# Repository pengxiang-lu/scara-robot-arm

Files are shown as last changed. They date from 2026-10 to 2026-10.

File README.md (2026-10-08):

# 下棋机器人：三轴 SCARA 机械臂控制系统

本项目是下棋机器人，包含三轴 SCARA 机械臂的 STM32 下位机固件、Qt 串口上位机，以及机械结构模型和设计文档。系统支持笛卡尔坐标运动、PS2 手柄控制、末端气泵取放和语音播报。

## 项目效果图

以下为三维模型中的整机装配视图：

| 整机俯视效果 | 整机正视效果 |
| --- | --- |
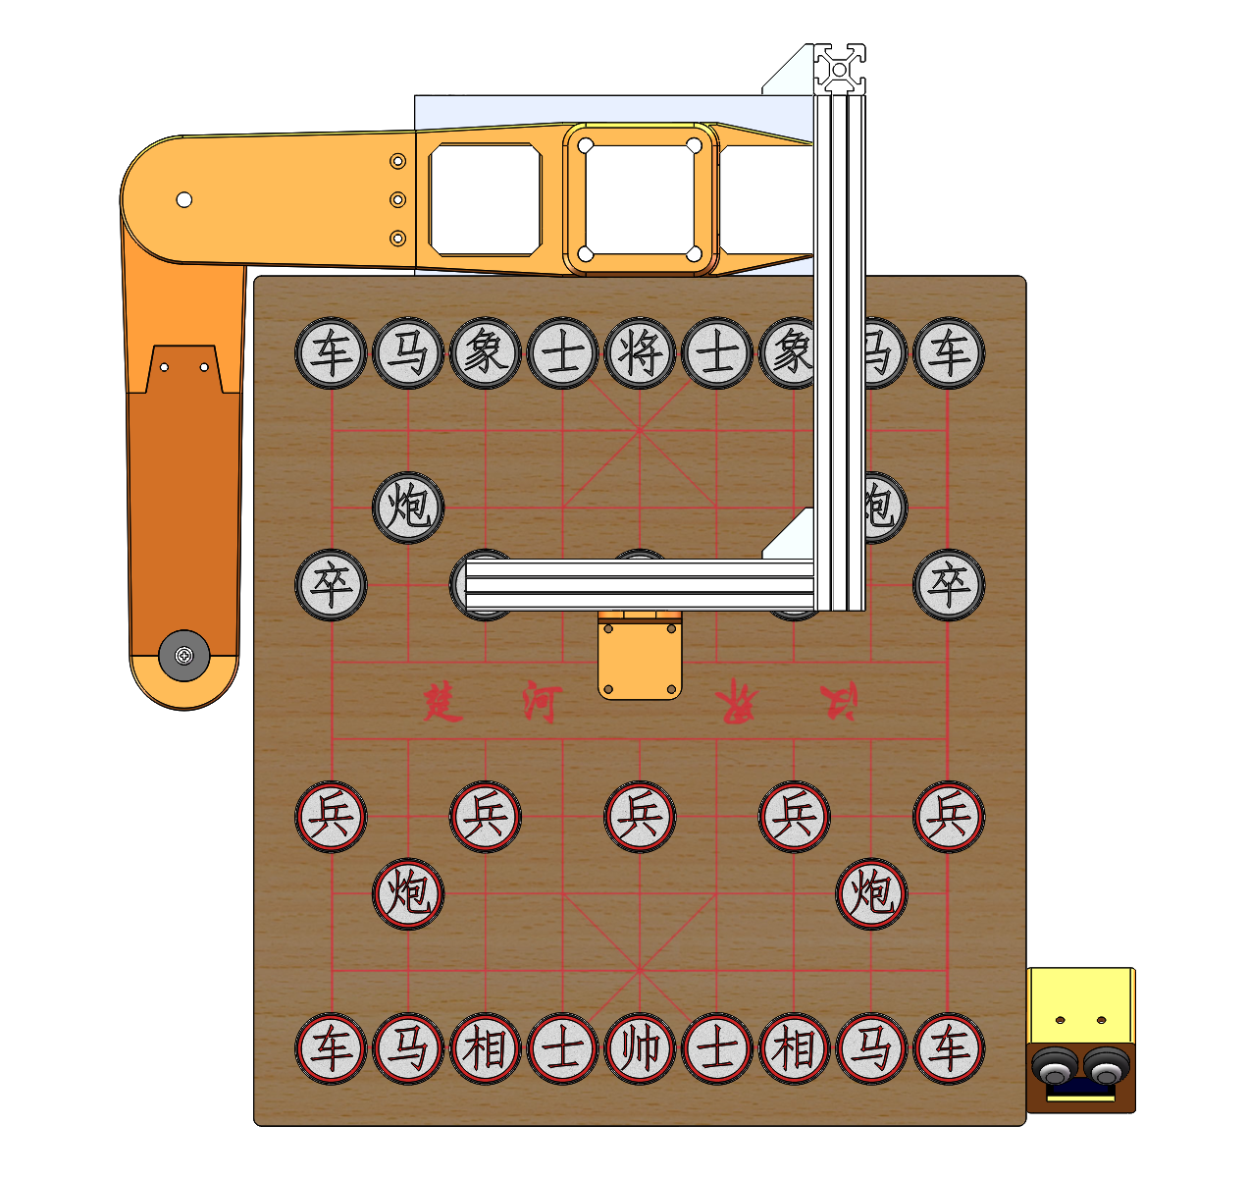
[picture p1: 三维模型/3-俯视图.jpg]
下棋机器人整机俯视三维效果图
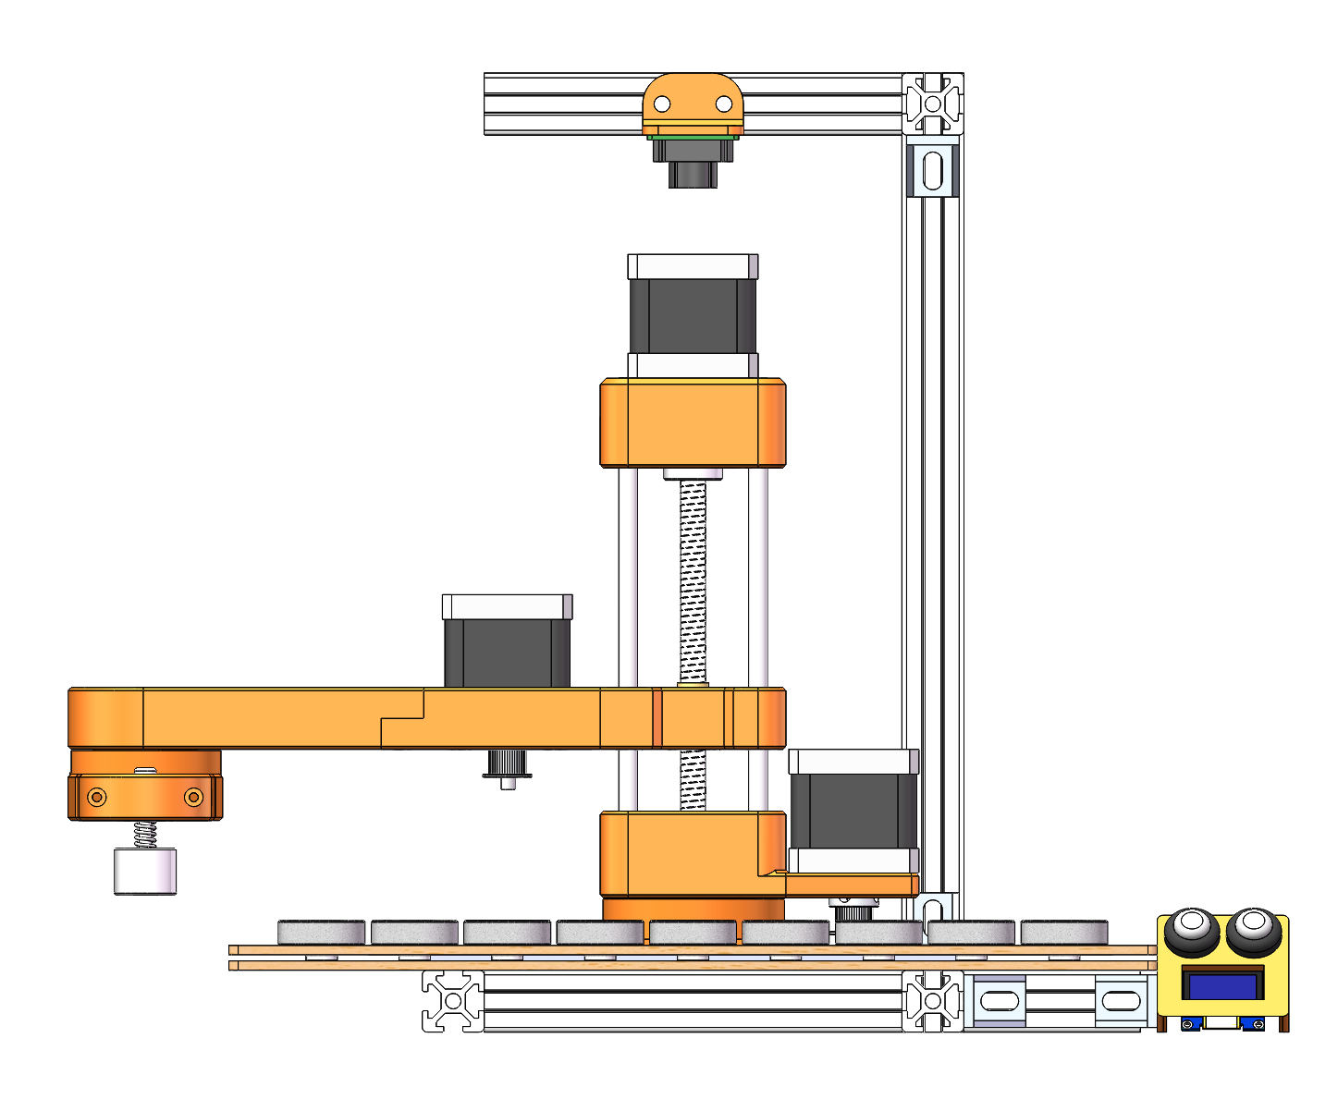
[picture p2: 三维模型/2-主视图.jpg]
下棋机器人整机正视三维效果图
|  |  |

真实照片：

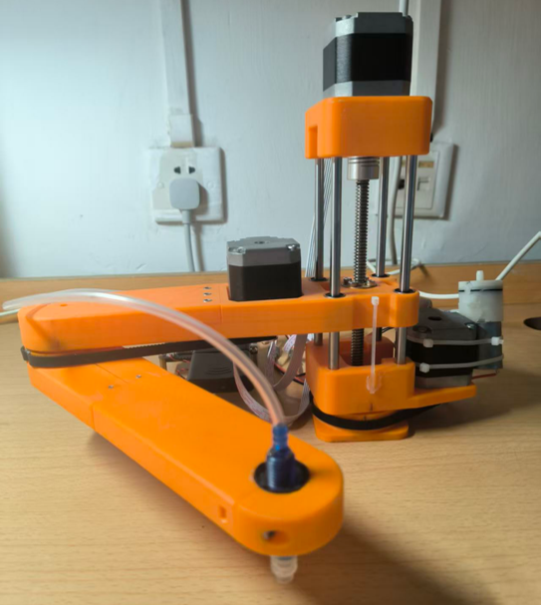
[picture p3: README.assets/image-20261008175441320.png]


驱动电路板：

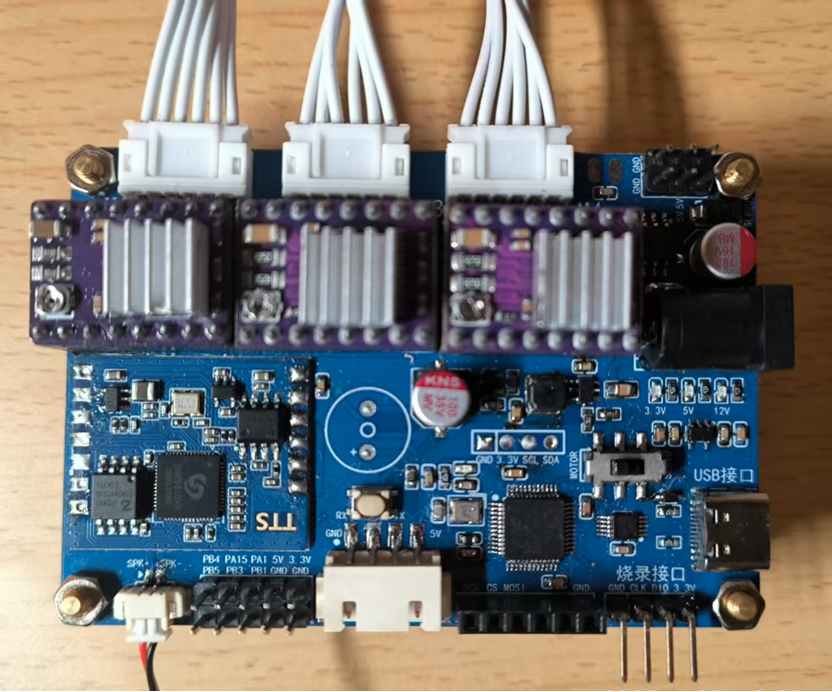
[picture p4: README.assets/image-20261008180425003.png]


上位机照片：

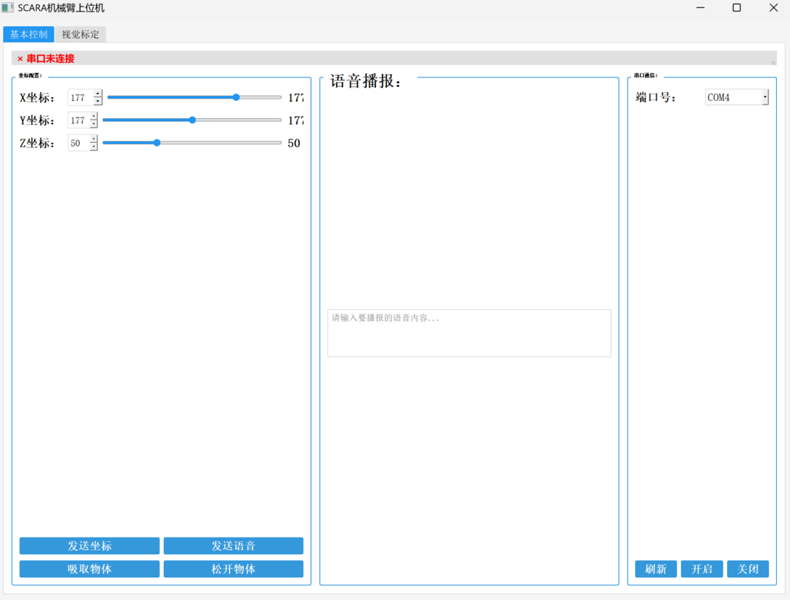
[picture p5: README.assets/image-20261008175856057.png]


	仿真照片：

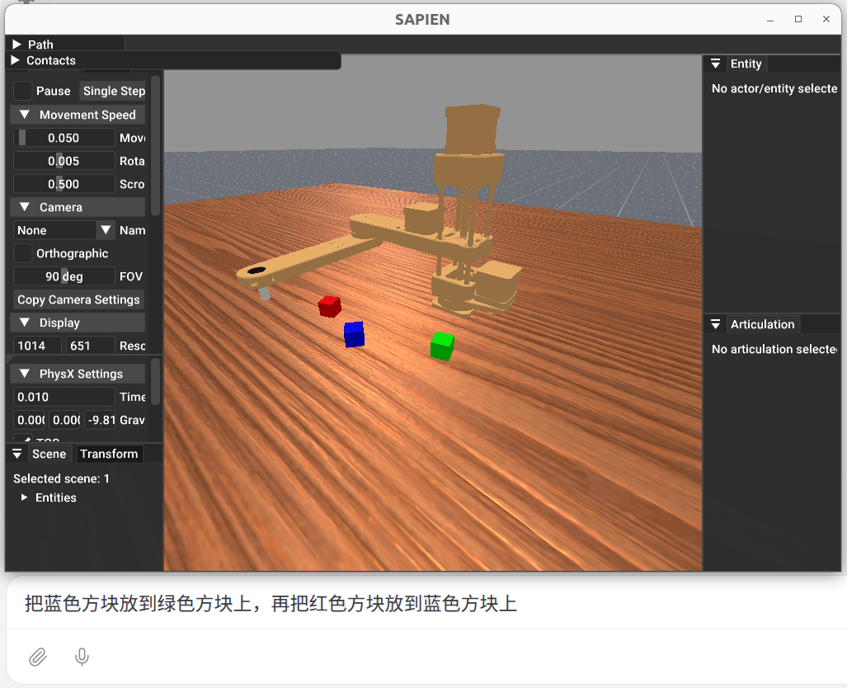
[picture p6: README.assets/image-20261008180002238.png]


## 功能概览

- **三轴 SCARA 运动控制**：下位机执行平面双连杆与 Z 轴运动学解算，将末端坐标转换为步进电机运动。
- **串口上位机控制**：通过 Qt 桌面程序选择串口、设置末端坐标、发送语音文本以及控制工具取放。
- **PS2 手柄遥控**：下位机读取手柄输入，支持直接控制机械臂末端及工具。
- **末端工具控制**：驱动气泵完成物块吸取和放下；固件配置中当前选择气泵方案。
- **语音播报**：通过串口向 SNR9816 模块发送文本。
- **机械结构与硬件资料**：提供机械臂、棋盘、PCB 等模型文件和设计笔记。

## 系统组成

| 部分 | 说明 |
| --- | --- |
| 下位机 | STM32F103C8，基于 STM32F10x 标准外设库；负责串口协议解析、运动学解算、三路步进电机、工具、PS2 和语音模块控制。 |
| 上位机 | Qt Widgets/C++ 桌面程序，使用 Qt SerialPort；提供串口连接、坐标控制、文本播报和工具控制。 |
| 机械结构 | 三轴 SCARA 机械臂，主、副臂长度参数各为 177 mm；步进电机经传动机构驱动。 |
| 驱动与供电 | 设计资料中包含 DRV8825 步进电机驱动、12 V 主电源及控制/语音模块供电方案；以实际装配和电路版本为准。 |

## 目录结构

```text
.
├── GUI/                         # Qt/C++ 上位机工程
│   ├── scara_HMI.pro             # qmake 工程文件
│   ├── mainwindow.*              # 界面与串口操作
│   └── roboticarm.*              # 上位机数据包封装
├── 下位机代码/                   # STM32 下位机工程
│   ├── Project.uvprojx            # Keil µVision 工程
│   ├── User/                      # main 与中断入口
│   ├── Hardware/                  # GPIO、串口、电机、语音等底层驱动
│   ├── Software/                  # SCARA 运动学、步进电机与协议逻辑
│   ├── Library/                   # STM32F10x 标准外设库
│   └── 通讯格式.txt               # 串口协议简表
├── URDF模型/                     # URDF 与网格模型
├── 三维模型/                     # 机械臂、棋盘及电路板等三维设计文件
└── 设计笔记/                     # 硬件与机械设计记录
```

## 构建与运行

### Qt 上位机

依赖：

- Qt 6（工程使用 C++17）
- Qt SerialPort 模块
- 与 Qt 套件匹配的 C++ 编译器（仓库现有构建目录对应 Qt 6.7.3 / MSVC 2019 64-bit Debug）

使用 Qt Creator 打开 [`GUI/scara_HMI.pro`](GUI/scara_HMI.pro)，选择已安装的桌面 Qt 套件，确认安装并启用 Qt SerialPort 后构建、运行。连接设备前，先通过界面刷新串口列表并选择端口。

上位机串口参数为 **115200 baud、8 数据位、无校验、1 停止位、无流控**。PC 与控制板之间需要使用匹配的 USB 转串口接口，并确保共地及电平兼容。

### STM32 下位机

使用 Keil MDK-ARM / µVision 打开 [`下位机代码/Project.uvprojx`](下位机代码/Project.uvprojx)。工程目标器件配置为 STM32F103C8，并依赖工程内的 STM32F10x 标准外设库。构建后按实际控制板的下载接口和时钟/引脚配置烧录固件。

上电后固件初始化电机、串口、语音模块和 PS2 手柄，并将末端坐标复位到 `X_INIT/Y_INIT/Z_INIT`。机械臂尺寸、减速比、Z 轴丝杆导程、运动范围等参数集中在 `下位机代码/Software/driver_config.h` 中；更改前请核对实际机构和驱动板配置。

> 首次联调请先断开或卸载末端工具，在安全范围内验证坐标和运动方向；坐标复位依赖当前固件设定，不等同于带限位开关的自动寻零。

## 串口协议

多字节坐标使用**大端序**传输，坐标在下位机侧按 `int16_t` 解释；校验和为指定字节求和后取低 8 位。坐标单位按固件中的机械尺寸参数以毫米配置。下列数据包均从上位机发往下位机。

| 包头 | 格式 | 校验/行为 |
| --- | --- | --- |
| `0x55` | `55 X高 X低 Y高 Y低 Z高 Z低 校验` | 校验为包头与 6 个坐标字节之和的低 8 位。下位机执行坐标移动；不可达时返回 `Target position unreachable\r\n`。 |
| `0x66` | `66 文本字节... 00` | 文本以 NUL 结尾，不带校验和。设计协议为 GBK 编码；发送端需与语音模块的字符编码保持一致。完成后返回 `Voice executed successfully\r\n`。 |
| `0x77` | `77 工具状态 校验` | `01` 吸取、`00` 放下；校验为包头与状态字节之和的低 8 位。 |
| `0x88` | `88 X高 X低 Y高 Y低 Z高 Z低 工具状态 校验` | 校验为包头及全部 7 个数据字节之和的低 8 位。依次执行工具状态变化和坐标移动；完成时返回 `Action executed successfully\r\n`，不可达时返回 `Target position unreachable\r\n`。 |

`0x55`、`0x77` 和 `0x88` 均由下位机校验后处理。上位机当前界面直接发送 `0x55`、`0x66` 和 `0x77`；`0x88` 可供兼容协议的客户端使用。

## 注意事项

- 运动范围和坐标系由固件配置及机械装配决定。更换连杆、传动比、丝杆或工具后，应重新校准参数并验证可达范围。
- 语音文本编码需与语音模块一致；Windows 上位机使用本地编码转换，跨系统运行时请特别检查字符编码。

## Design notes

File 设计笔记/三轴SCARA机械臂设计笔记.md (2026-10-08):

# 三轴SCARA机械臂设计笔记

## 一、机械

### 1. 机械臂

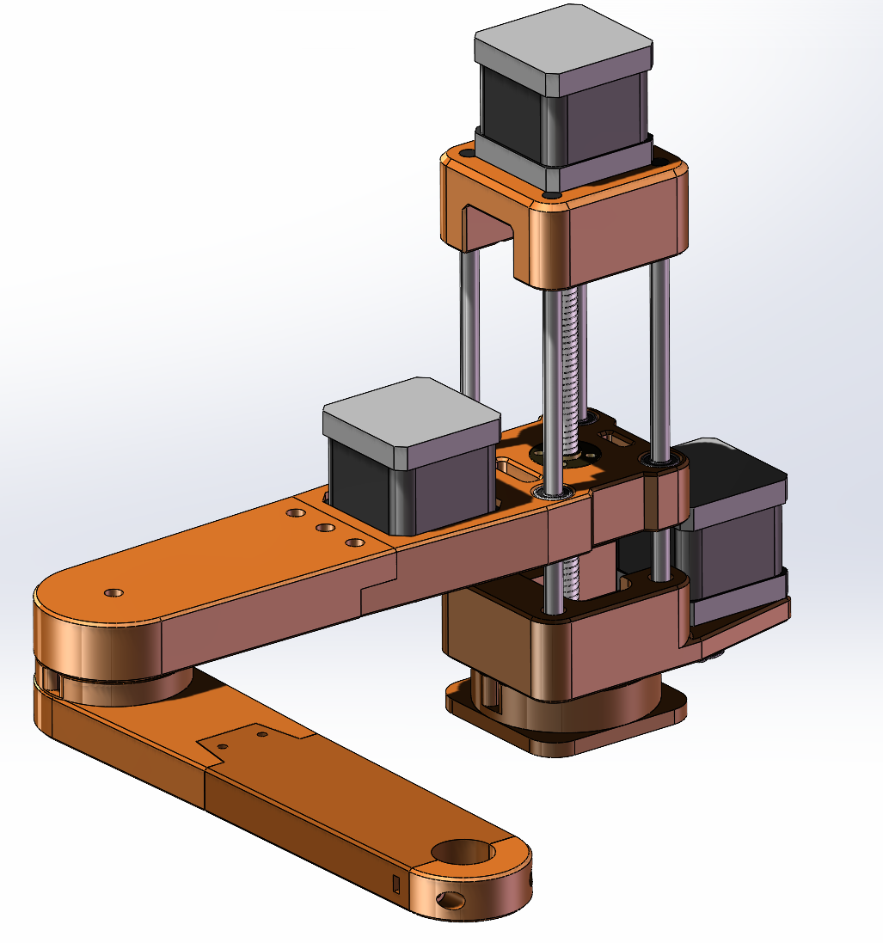
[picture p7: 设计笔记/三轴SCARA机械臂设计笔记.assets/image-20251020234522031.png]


使用的机械臂是复刻了网络上开源的一个三轴SCARA机械臂（https://community.aijishu.com/a/1060000000361674），使用三个步进电机加上皮带传动驱动机械臂的运动，机械臂3D模型如上图所示。

### 2. 步进电机

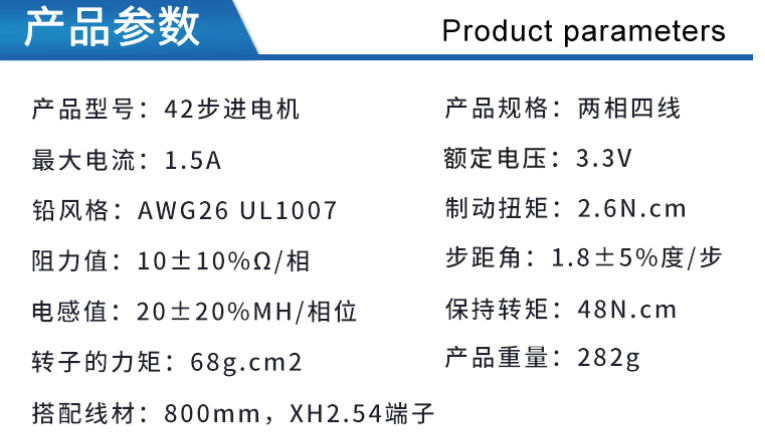
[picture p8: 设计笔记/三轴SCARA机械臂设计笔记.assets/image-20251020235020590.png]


这是使用的步进电机的参数，产品介绍上面写的是3.3V额定电压，然后问了厂家实际上9~36V的电机供电电压都可以。所以设计上采用常用的12V供电。

### 3. 电磁铁

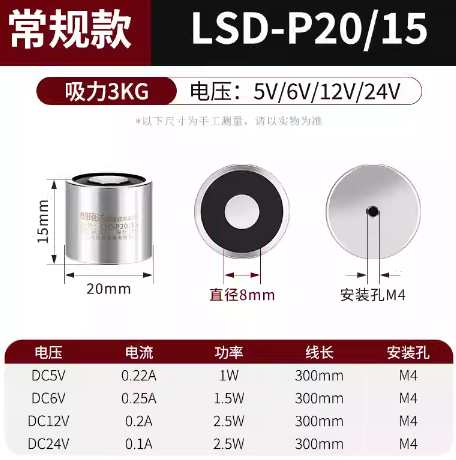
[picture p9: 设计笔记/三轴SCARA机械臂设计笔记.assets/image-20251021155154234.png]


使用了12V的电磁铁来吸取棋子。

但是后面发现对棋子的吸力不够而且只能吸附磁性物体。

所以后面更改了方案，使用气泵和磁通阀来实现物体的拾取。

### 4. 气泵

电磁铁只能吸取磁性物体，而且对棋子的吸力不足，因此改用气泵配合气路末端吸盘完成取放。气泵由下位机控制，取物和放物分别执行不同的输出时序。

当前固件在 `driver_config.h` 中将 `TOOL` 配置为 `AIRPUMP`。`tool.c` 使用 TIM1 的两个 PWM 通道控制气泵相关输出，PWM 频率为 50 Hz；取物和放物时切换通道的比较值，并各延时约 800 ms。气泵及阀的具体型号、气路连接方式和 PWM 比较值与实际执行器的对应关系，应以实物接线和调试结果为准。

## 二、硬件

使用语音播报，三路步进电机驱动，一路有刷电机驱动，还要有远程控制的下位机电路，所以下面考虑如何设计这个电路。

### 1. 语音模块

理论上可以使用直接像DY-SV17F这样的USB提前下载要播报语音的模块，但是打算使用SNR9816TTS模块来实现语音播报。

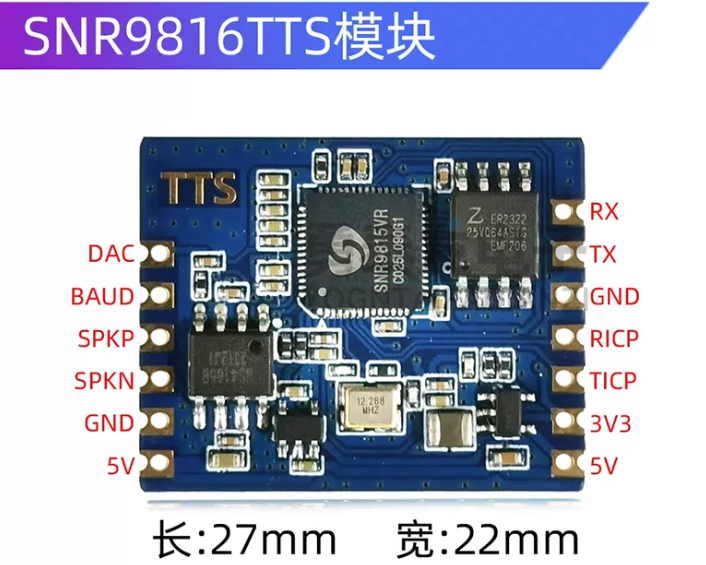
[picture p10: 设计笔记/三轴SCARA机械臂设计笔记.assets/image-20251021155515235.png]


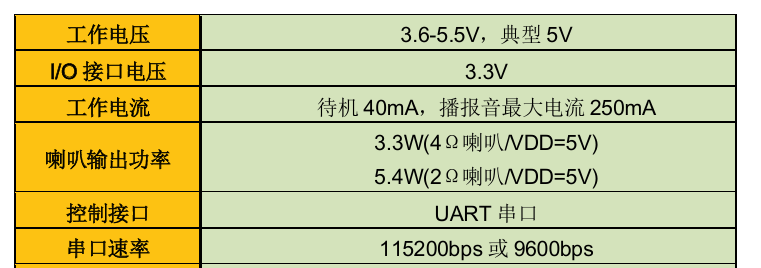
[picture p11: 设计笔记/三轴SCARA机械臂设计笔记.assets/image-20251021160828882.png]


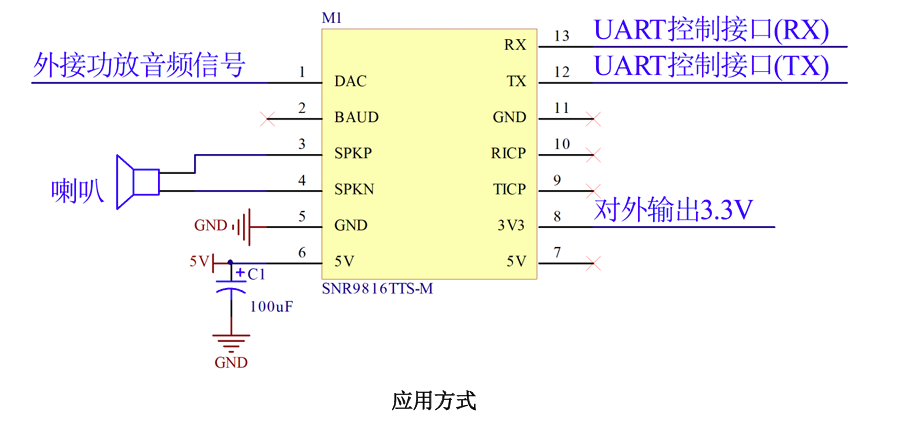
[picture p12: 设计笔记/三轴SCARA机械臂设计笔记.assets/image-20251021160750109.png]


### 2. 步进电机驱动模块

由于电机参数上面写的是最高电流1.5A，所以采用DRV8825绰绰有余，而且比传统的A4988步进电机驱动的要好用很多。

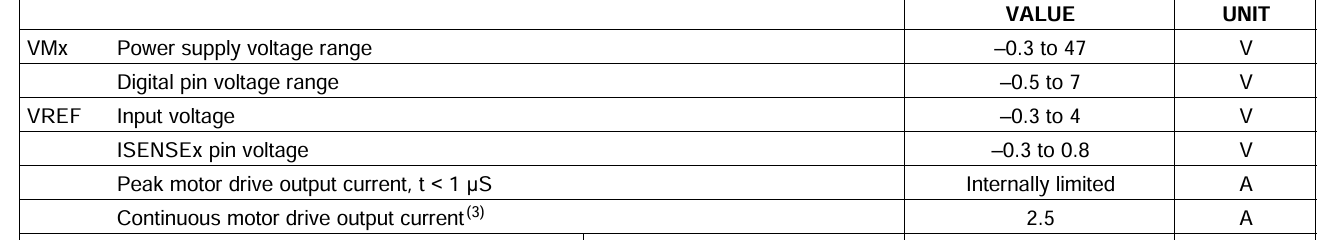
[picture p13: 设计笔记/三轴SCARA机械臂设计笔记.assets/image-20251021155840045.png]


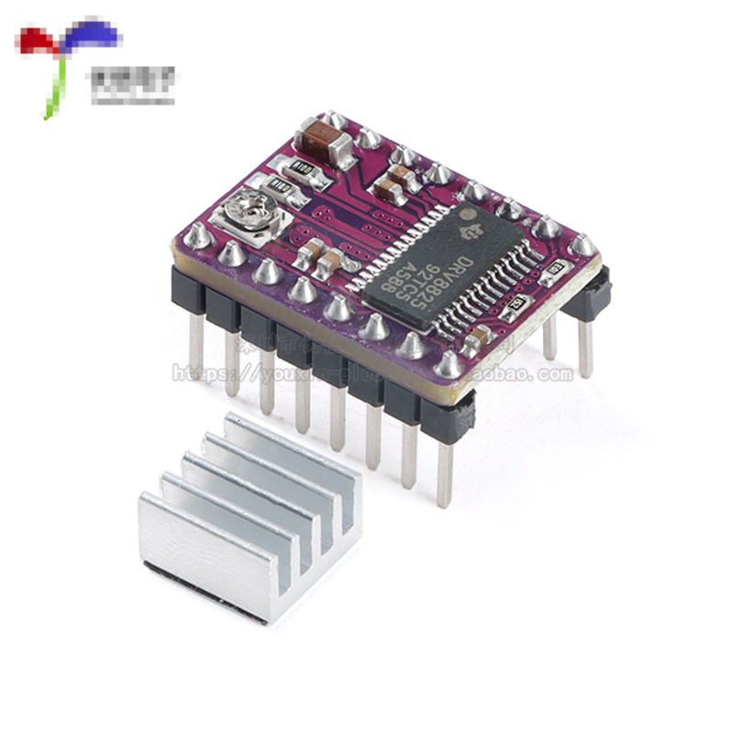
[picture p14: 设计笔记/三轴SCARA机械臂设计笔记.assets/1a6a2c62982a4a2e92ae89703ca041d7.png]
1a6a2c62982a4a2e92ae89703ca041d7


### 3. 有刷电机驱动模块

由于只需要一路有刷电机驱动，而且电流要求较小，所以电机采用L9110S电机驱动，工作电压2.5V~12V，最大持续电流1.2A，最大电流2A满足电流需求。这是手册里给的参考电路：

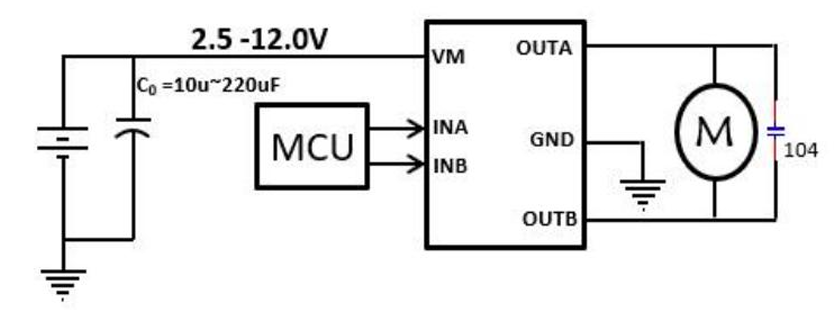
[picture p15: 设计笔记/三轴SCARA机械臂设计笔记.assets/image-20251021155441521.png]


### 4. 电源树

由于使用的是12V主电源供电和3.3V控制电路供电，而且语音播报模块要5V供电，所以要分别将12V降压到5V和3.3V，所以可以使用如下方案：

首先使用TPS563201这款DCDC电源芯片将电压降到5V，再通过LDO将5V电压降压到3.3V。原理图如下：

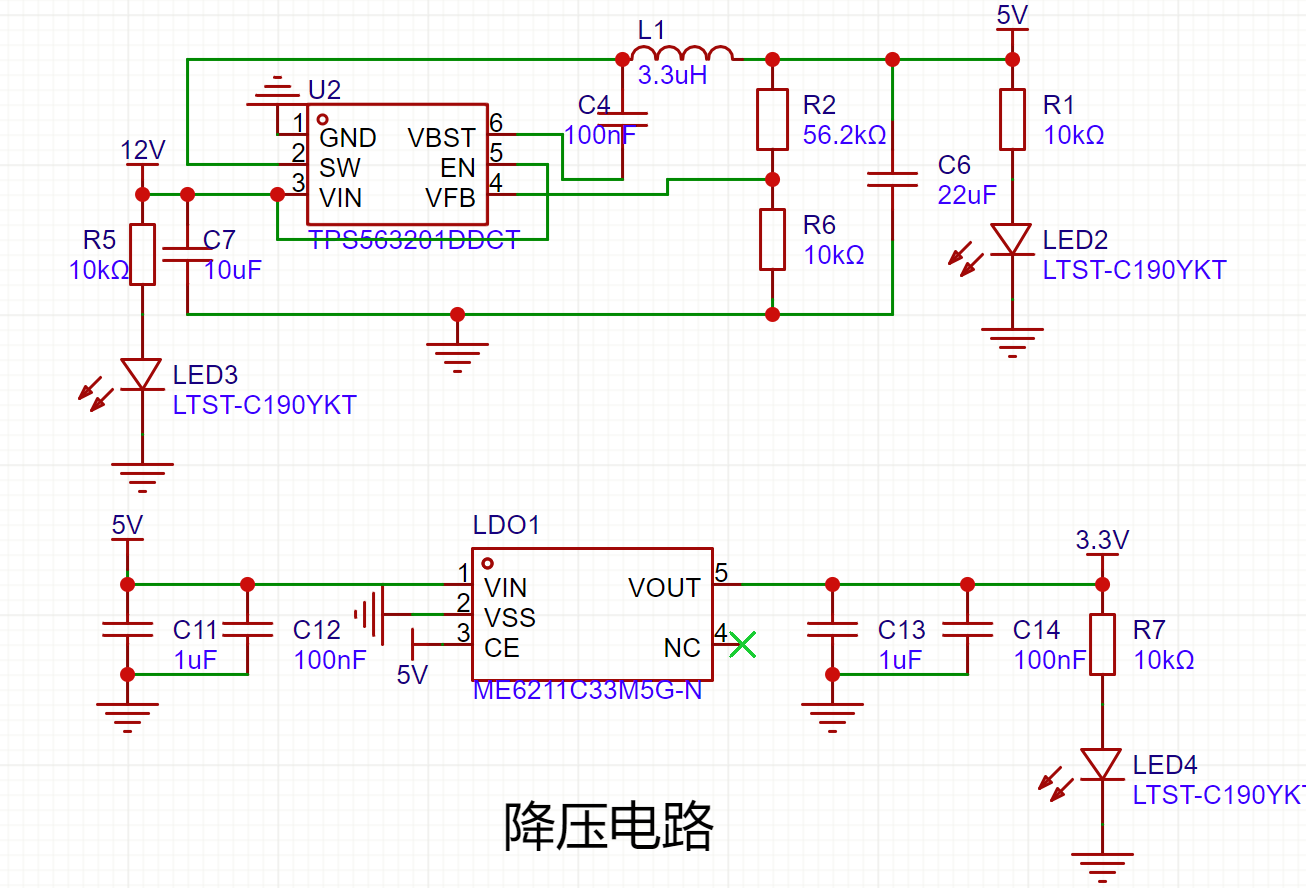
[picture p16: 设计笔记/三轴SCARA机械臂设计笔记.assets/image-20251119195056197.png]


## 三、下位机控制算法

### 1. 步进电机驱动

机械臂的 FA（主臂）、SA（副臂）和 Z（垂直丝杆）轴均使用步进电机。固件将电机步距角配置为 1.8°，细分数配置为 32；驱动器接收方向信号和脉冲信号，下位机分别使用 TIM2、TIM3、TIM4 产生三轴脉冲。PWM 占空比约为 50%，通过改变定时器自动重装载值调整脉冲频率，脉冲数决定电机的目标步数。

电机初始化时将角度和速度参数换算为细分脉冲参数。每个关节的脉冲数与角度关系为：

```text
每度脉冲数 = 细分数 / 步距角
目标脉冲数 = 目标角度变化 × 每度脉冲数 × 传动比
```

FA、SA 轴分别使用 5.1 和 3.9 的传动比；Z 轴根据 2 mm 导程换算，即每转对应 2 mm 的直线位移。运动过程中，固件按目标脉冲数和设定速度规划加速、匀速及减速区间：加速与减速过程依据匀加速关系计算脉冲速度，再换算成定时器周期；短距离运动无法达到最高速度时，则缩短加减速区间。定时器更新中断负责累计已输出的脉冲，达到目标脉冲数后停止对应定时器。三轴运动分别运行，主循环等待各轴完成后结束本次坐标移动。

当前固件中 FA、SA 初始化参数为加速度 50°/s²、最高速度 30°/s、最低速度 10°/s；Z 轴电机初始化参数为加速度 80°/s²、最高速度 80°/s、最低速度 15°/s（按电机转角速度配置，再通过丝杆导程换算为直线运动）。修改这些参数前，应结合电机、驱动器电流、负载和机械传动进行实际测试。

### 2. 机械臂解算

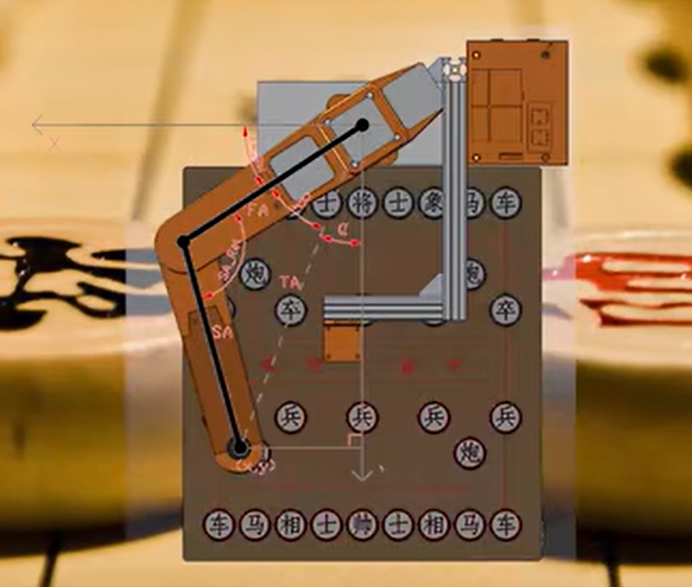
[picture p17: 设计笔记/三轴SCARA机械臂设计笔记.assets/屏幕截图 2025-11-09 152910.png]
屏幕截图 2025-11-09 152910


	这是机械臂的三个轴的定义：FA（主臂），SA（副臂），Z（垂直丝杆）

机械臂在 XY 平面内由两段连杆构成，FA 为主臂关节，SA 为副臂关节；Z 轴通过丝杆带动末端上下移动。固件参数中两段连杆长度均为 177 mm，末端坐标使用毫米表示。

上位机发送末端坐标 `(x, y, z)` 后，下位机先进行逆运动学求解。令 `L1`、`L2` 分别为两段连杆长度，`r² = x² + y²`，按当前固件采用的坐标轴和关节角定义计算：

```text
r² = x² + y²
SA = acos((L1² + L2² - r²) / (2 × L1 × L2)) × 180° / π
alpha = atan2(-y, x) × 180° / π
beta = acos((L1² + r² - L2²) / (2 × L1 × sqrt(r²))) × 180° / π
FA = 90° - alpha - beta
```

三角函数求解得到的角度换算为度数后，再与关节限位比较。当前固件配置的 FA 范围为 -90° 至 90°，SA 范围为 15° 至 180°，Z 高度范围为 2 mm 至 83 mm；超出连杆可达区域或关节限位时拒绝运动。通过检查后，下位机根据目标角度差、传动比、细分数以及 Z 轴导程计算各电机的目标脉冲数，并驱动三轴运动。

坐标初始化目前使用固件中设定的 `(177, -177, 25)`，这是程序写入的初始坐标，并非限位开关或编码器反馈得到的真实机械原点。搬运机构或机械臂时应重新确认初始姿态和坐标对应关系。

**实现注意：**逆运动学得到的关节角以度为单位；检查或使用正运动学实现时，应确认传入 `sin`/`cos` 的角度已转换为弧度，并验证关节角定义与图中的坐标轴方向一致。

## 四、物料清单

暂定

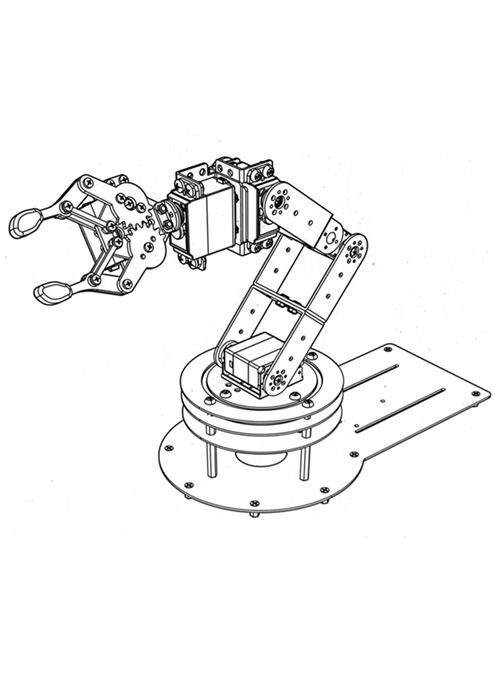
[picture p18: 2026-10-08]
GUI/image/robotic_arm_image.png

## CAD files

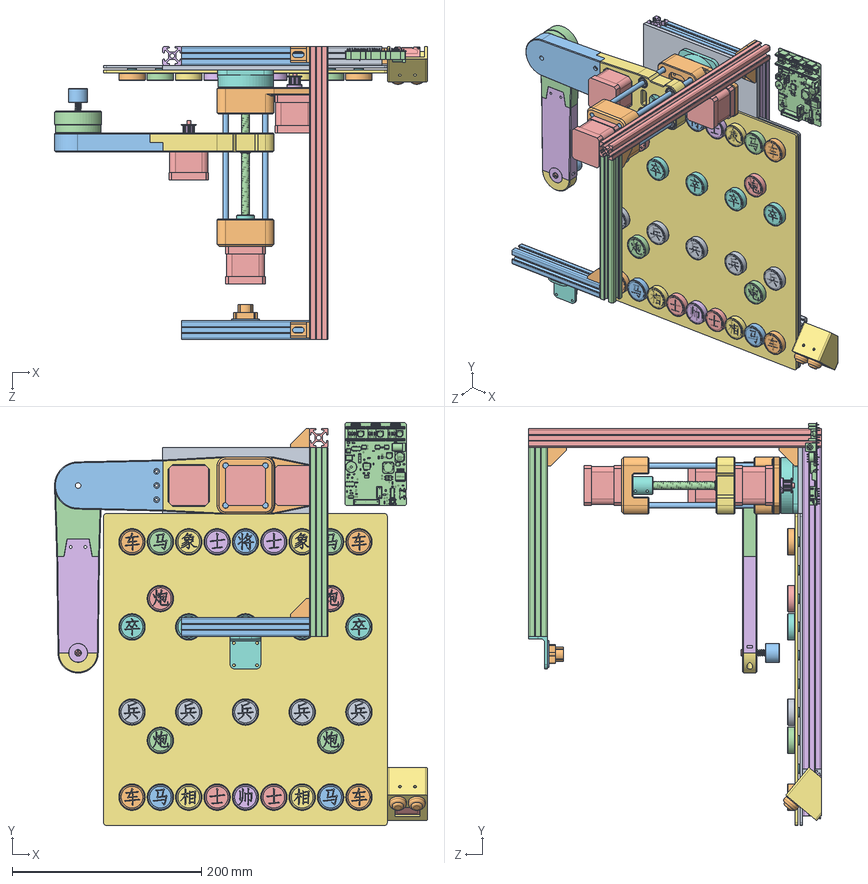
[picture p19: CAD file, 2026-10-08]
三维模型/总装配体/象棋机器人装配体.SLDASM
394.5 x 426.2 x 310.0 mm
亚克力底座
2020角件 x 12
2020型材135mm x 4
2020型材200mm
2020型材310mm
2020型材390mm x 2
棋盘正面
磁铁 x 122
棋盘底面
棋子-黑車 x 2
棋子-黑将
棋子-黑马 x 2
棋子-黑炮 x 2
棋子-黑士 x 2
棋子-黑象 x 2
棋子-黑卒 x 5
棋子-红兵 x 5
棋子-红車 x 2
棋子-红马 x 2
棋子-红炮 x 2
棋子-红士 x 2
棋子-红帅
棋子-红相 x 2
x轴底座
6806轴承 x 2
x轴转台
光轴 x 4
丝杆
42步进 x 3
GT2同步轮内孔5 x 2
x轴主臂1
联轴器
直线轴承 x 4
顶(丝杆z)
x轴主臂2加长3
y轴对称
686zz x 4
y轴副臂2加长3
末端固定
T8螺母
按钮螺母-新款 x 2
按钮-新款 x 2
电磁铁
电磁铁弹簧
电磁铁固定螺栓
电磁铁套筒
屏幕外壳3
摄像头支架
屏幕连接型材
mount lens
PCB
OLED模块

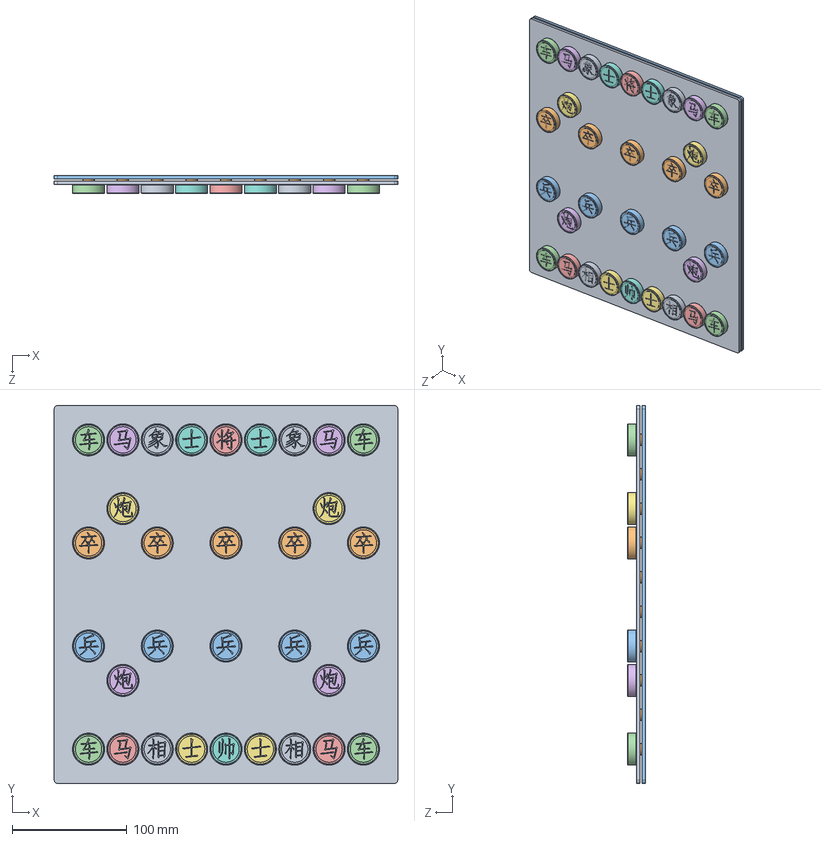
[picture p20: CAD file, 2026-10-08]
三维模型/棋盘装配体/棋盘装配体.SLDASM
300.0 x 330.0 x 16.0 mm
棋盘正面
磁铁 x 122
棋盘底面
棋子-黑車 x 2
棋子-黑将
棋子-黑马 x 2
棋子-黑炮 x 2
棋子-黑士 x 2
棋子-黑象 x 2
棋子-黑卒 x 5
棋子-红兵 x 5
棋子-红車 x 2
棋子-红马 x 2
棋子-红炮 x 2
棋子-红士 x 2
棋子-红帅
棋子-红相 x 2

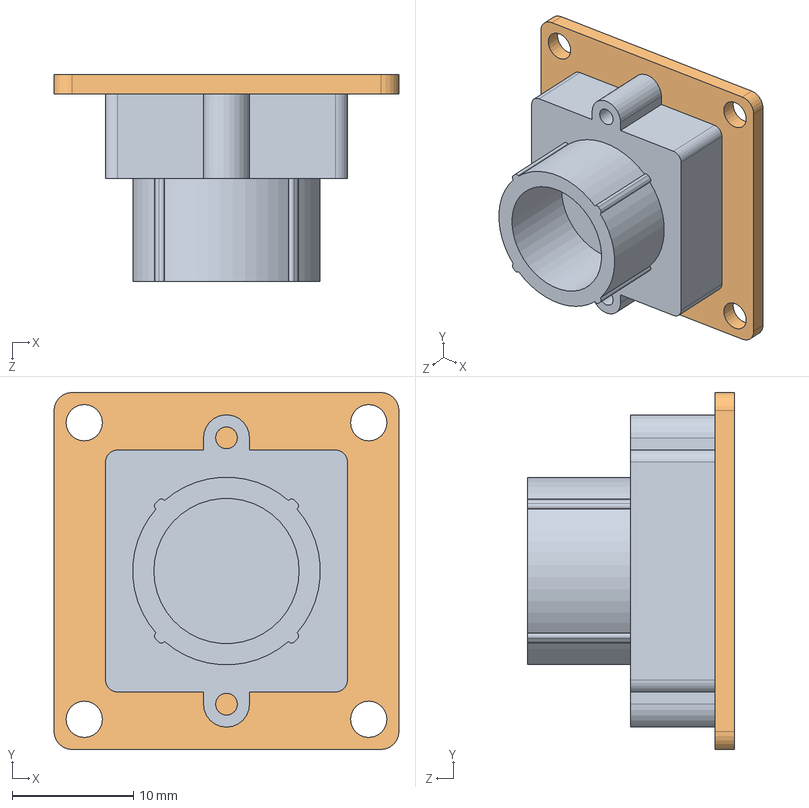
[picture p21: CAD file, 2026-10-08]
三维模型/摄像头装配体/摄像头.SLDASM
28.5 x 29.5 x 17.1 mm
mount lens
PCB

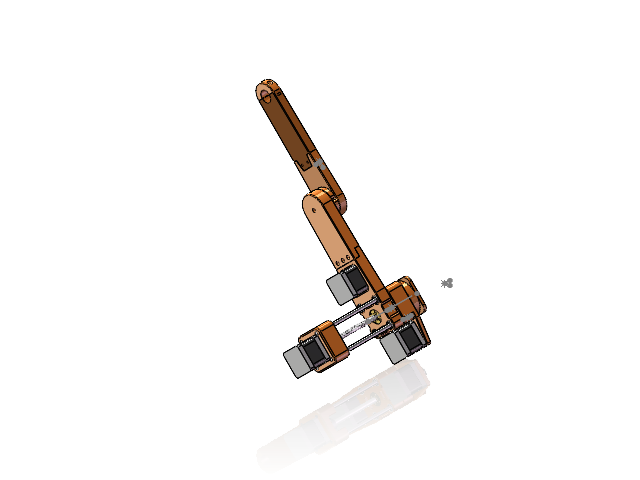
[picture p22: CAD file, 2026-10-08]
三维模型/机械臂装配体/机械臂装配体.SLDASM
x轴底座
6806轴承 x 2
x轴转台
光轴 x 4
丝杆
42步进 x 3
GT2同步轮内孔5 x 2
x轴主臂1
联轴器
直线轴承 x 4
顶(丝杆z)
x轴主臂2加长3
y轴对称
686zz x 4
y轴副臂2加长3
末端固定
T8螺母

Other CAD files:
三维模型/PCBv3.2装配体/C14.sldasm
三维模型/PCBv3.2装配体/J1.sldasm
三维模型/PCBv3.2装配体/R1.sldasm
三维模型/PCBv3.2装配体/U7.sldasm
三维模型/PCBv3.2装配体/C16.sldasm
三维模型/PCBv3.2装配体/D3.sldasm
三维模型/PCBv3.2装配体/D4.sldasm
三维模型/PCBv3.2装配体/C33.sldasm
三维模型/PCBv3.2装配体/R5.sldasm
三维模型/PCBv3.2装配体/U10.sldasm
三维模型/PCBv3.2装配体/U8.sldasm
三维模型/PCBv3.2装配体/U6.sldasm
三维模型/PCBv3.2装配体/C20.sldasm
三维模型/PCBv3.2装配体/R32.sldasm
URDF模型/scara_urdf/meshes/Link1.STL
URDF模型/scara_urdf/meshes/Link2.STL
URDF模型/scara_urdf/meshes/Link3.STL
URDF模型/scara_urdf/meshes/base_link.STL
URDF模型/scara_urdf_gripper/meshes/Link1.STL
URDF模型/scara_urdf_gripper/meshes/Link2.STL
URDF模型/scara_urdf_gripper/meshes/Link3.STL
URDF模型/scara_urdf_gripper/meshes/base_link.STL
URDF模型/scara_urdf_gripper/meshes/finger.stl
URDF模型/scara_urdf_gripper/meshes/hand.stl
URDF模型/scara_urdf_suction/meshes/Link1.STL
URDF模型/scara_urdf_suction/meshes/Link2.STL
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

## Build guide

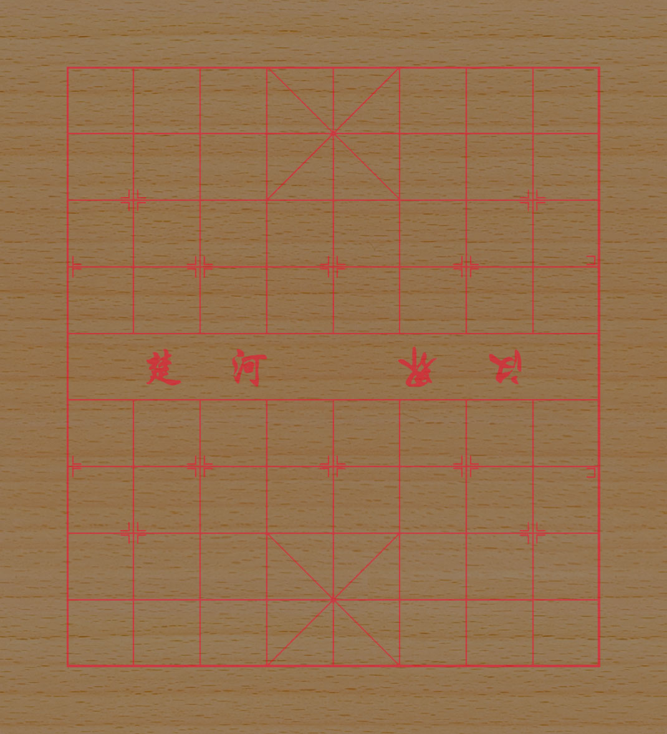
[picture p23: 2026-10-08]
三维模型/棋盘装配体/桉木棋盘.jpg

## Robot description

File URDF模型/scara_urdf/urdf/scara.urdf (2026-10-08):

<?xml version="1.0" encoding="utf-8"?>
<!-- This URDF was automatically created by SolidWorks to URDF Exporter! Originally created by Stephen Brawner (brawner@gmail.com) 
     Commit Version: 1.6.0-4-g7f85cfe  Build Version: 1.6.7995.38578
     For more information, please see http://wiki.ros.org/sw_urdf_exporter -->
<robot name="scara">
  <link name="base_link">
    <inertial>
      <origin xyz="-2.33602825269394E-08 0.000325855492130904 0.00700152226621419" rpy="0 0 0" />
      <mass value="0.0402568517427835" />
      <inertia ixx="1.16860689250314E-05" ixy="-1.8570220883558E-11" ixz="5.64103689843095E-12" iyy="1.1993754297666E-05" iyz="-7.8687526683924E-08" izz="2.18256266420959E-05" />
    </inertial>
    <visual>
      <origin xyz="0 0 0" rpy="0 0 0" />
      <geometry>
        <mesh filename="package://scara/meshes/base_link.STL" />
      </geometry>
      <material name="">
        <color rgba="1 0.533333333333333 0.176470588235294 1" />
      </material>
    </visual>
    <collision>
      <origin xyz="0 0 0" rpy="0 0 0" />
      <geometry>
        <mesh filename="package://scara/meshes/base_link.STL" />
      </geometry>
    </collision>
  </link>
  <link name="Link1">
    <inertial>
      <origin xyz="-5.82317828406263E-05 0.0125670372099185 0.106258424386727" rpy="0 0 0" />
      <mass value="0.326072004656768" />
      <inertia ixx="0.000175710230688168" ixy="1.48740556515632E-09" ixz="-1.85135692980239E-07" iyy="0.000155118181724295" iyz="5.77187163494193E-06" izz="0.000168999196132045" />
    </inertial>
    <visual>
      <origin xyz="0 0 0" rpy="0 0 0" />
      <geometry>
        <mesh filename="package://scara/meshes/Link1.STL" />
      </geometry>
      <material name="">
        <color rgba="1 0.533333333333333 0.176470588235294 1" />
      </material>
    </visual>
    <collision>
      <origin xyz="0 0 0" rpy="0 0 0" />
      <geometry>
        <mesh filename="package://scara/meshes/Link1.STL" />
      </geometry>
    </collision>
  </link>
  <joint name="joint1" type="revolute">
    <origin xyz="0 0 0" rpy="0 0 0" />
    <parent link="base_link" />
    <child link="Link1" />
    <axis xyz="0 0 1" />
    <limit lower="-1.57" upper="1.57" effort="0" velocity="0" />
  </joint>
  <link name="Link2">
    <inertial>
      <origin xyz="0.0757980106992246 -2.08571677094531E-06 -0.0051586157715495" rpy="0 0 0" />
      <mass value="0.269351505596376" />
      <inertia ixx="7.65002539967446E-05" ixy="-2.60368605877457E-09" ixz="3.17859629830699E-06" iyy="0.000236767952686508" iyz="2.56350182000798E-09" izz="0.000281158978903039" />
    </inertial>
    <visual>
      <origin xyz="0 0 0" rpy="0 0 0" />
      <geometry>
        <mesh filename="package://scara/meshes/Link2.STL" />
      </geometry>
      <material name="">
        <color rgba="1 0.533333333333333 0.176470588235294 1" />
      </material>
    </visual>
    <collision>
      <origin xyz="0 0 0" rpy="0 0 0" />
      <geometry>
        <mesh filename="package://scara/meshes/Link2.STL" />
      </geometry>
    </collision>
  </link>
  <joint name="joint2" type="prismatic">
    <origin xyz="0 0 0.0664" rpy="0 0 -1.5708" />
    <parent link="Link1" />
    <child link="Link2" />
    <axis xyz="0 0 1" />
    <limit lower="0" upper="0.091" effort="50" velocity="1" />
  </joint>
  <link name="Link3">
    <inertial>
      <origin xyz="0.0714052178204697 0.000746521706669515 -0.0279252348818434" rpy="0 0 0" />
      <mass value="0.155288189008471" />
      <inertia ixx="3.10970726600027E-05" ixy="-7.56646280633992E-07" ixz="5.77430535141398E-06" iyy="0.000121028450793099" iyz="-2.31665870998517E-09" izz="0.00014171550680783" />
    </inertial>
    <visual>
      <origin xyz="0 0 0" rpy="0 0 0" />
      <geometry>
        <mesh filename="package://scara/meshes/Link3.STL" />
      </geometry>
      <material name="">
        <color rgba="1 0.533333333333333 0.176470588235294 1" />
      </material>
    </visual>
    <collision>
      <origin xyz="0 0 0" rpy="0 0 0" />
      <geometry>
        <mesh filename="package://scara/meshes/Link3.STL" />
      </geometry>
    </collision>
  </link>
  <joint name="joint3" type="revolute">
    <origin xyz="0.177 0 -0.0061" rpy="0 0 0" />
    <parent link="Link2" />
    <child link="Link3" />
    <axis xyz="0 0 -1" />
    <limit lower="-2.8" upper="0" effort="0" velocity="0" />
  </joint>
</robot>

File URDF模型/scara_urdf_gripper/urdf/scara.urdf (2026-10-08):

<?xml version="1.0" encoding="utf-8"?>
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
<robot name="scara_with_gripper">

  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
  <link name="base_link">
    <inertial>
      <origin xyz="-2.33602825269394E-08 0.000325855492130904 0.00700152226621419" rpy="0 0 0" />
      <mass value="0.0402568517427835" />
      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
    </inertial>
    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
  </link>

  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
  <link name="Link1">
    <inertial>
      <origin xyz="-5.82317828406263E-05 0.0125670372099185 0.106258424386727" rpy="0 0 0" />
      <mass value="0.326072004656768" />
      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
    </inertial>
    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
  </link>

  <joint name="joint1" type="revolute">
    <origin xyz="0 0 0" rpy="0 0 0" />
    <parent link="base_link" />
    <child link="Link1" />
    <axis xyz="0 0 1" />
    <limit lower="-1.57" upper="1.57" effort="0" velocity="0" />
  </joint>

  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
  <link name="Link2">
    <inertial>
      <origin xyz="0.0757980106992246 -2.08571677094531E-06 -0.0051586157715495" rpy="0 0 0" />
      <mass value="0.269351505596376" />
      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
    </inertial>
    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
  </link>

  <joint name="joint2" type="prismatic">
    <origin xyz="0 0 0.0864" rpy="0 0 -1.5708" />
    <parent link="Link1" />
    <child link="Link2" />
    <axis xyz="0 0 1" />
    <limit lower="0.00" upper="0.071" effort="50" velocity="1" />
  </joint>

  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
  <link name="Link3">
    <inertial>
      <origin xyz="0.0714052178204697 0.000746521706669515 -0.0279252348818434" rpy="0 0 0" />
      <mass value="0.155288189008471" />
      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
    </inertial>
    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
  </link>

  <joint name="joint3" type="revolute">
    <origin xyz="0.177 0 -0.0061" rpy="0 0 0" />
    <parent link="Link2" />
    <child link="Link3" />
    <axis xyz="0 0 -1" />
    <limit lower="-2.8" upper="0" effort="0" velocity="0" />
  </joint>

  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
  <joint name="scara_to_gripper_joint" type="revolute">
    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
    <origin rpy="3.14 0 0" xyz="0.177 0 -0.03"/>
    <parent link="Link3"/>
    <child link="panda_hand"/>
    <axis xyz="0 0 -1" />
    <limit lower="-3.14" upper="3.14" effort="0" velocity="0" />
  </joint>

  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
  <link name="panda_hand">
    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
    <inertial>
      <origin rpy="0 0 0" xyz="-0.01 0 0.03"/>
      <mass value="0.73"/>
      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
    </inertial>
  </link>

  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
  <link name="panda_hand_tcp"/>
  <joint name="panda_hand_tcp_joint" type="fixed">
    <origin rpy="0 0 0" xyz="0 0 0.050"/>
    <parent link="panda_hand"/>
    <child link="panda_hand_tcp"/>
  </joint>

  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
  <link name="panda_leftfinger">
    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
    <inertial>
      <origin rpy="0 0 0" xyz="0 0 0"/>
      <mass value="0.015"/>
      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
    </inertial>
  </link>

  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
  <link name="panda_rightfinger">
    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
    <inertial>
      <origin rpy="0 0 0" xyz="0 0 0"/>
      <mass value="0.015"/>
      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
    </inertial>
  </link>

  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
  <link name="panda_leftfinger_pad"/>
  <joint name="panda_leftfinger_pad_joint" type="fixed">
    <origin rpy="0 0 0" xyz="0 0 0.02"/>
    <parent link="panda_leftfinger"/>
    <child link="panda_leftfinger_pad"/>
  </joint>

  <link name="panda_rightfinger_pad"/>
  <joint name="panda_rightfinger_pad_joint" type="fixed">
    <origin rpy="0 0 0" xyz="0 0 0.02"/>
    <parent link="panda_rightfinger"/>
    <child link="panda_rightfinger_pad"/>
  </joint>

  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
  <joint name="panda_finger_joint1" type="prismatic">
    <parent link="panda_hand"/>
    <child link="panda_leftfinger"/>
    <origin rpy="0 0 0" xyz="0 0 0.0204"/>
    <axis xyz="0 1 0"/>
    <limit effort="100" lower="0.0" upper="0.035" velocity="0.2"/>
    <dynamics damping="0.3"/>
  </joint>

  <joint name="panda_finger_joint2" type="prismatic">
    <parent link="panda_hand"/>
    <child link="panda_rightfinger"/>
    <origin rpy="0 0 0" xyz="0 0 0.0204"/>
    <axis xyz="0 -1 0"/>
    <limit effort="100" lower="0.0" upper="0.035" velocity="0.2"/>
    <dynamics damping="0.3"/>
  </joint>

</robot>

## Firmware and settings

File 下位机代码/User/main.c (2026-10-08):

#include "driver_config.h"
scara_struct scara;
extern uint8_t scara_uart_flag;
int main(void)
{
	delay_init();								// 延时初始化
	
	interface_init();							// 底层接口函数与结构体的绑定初始化
	
	interrupt_global_disable();					// 关闭所有中断
	 
	scara_init(&scara);							// 机械臂初始化，最大速度 50度/s,加速度 500度/s^2
	
	gpio_init();								// gpio初始化	
	
	computer_serial_init();						// 与上位机通信串口初始化
	
	lcd_serial_init();							// 与串口屏通信初始化
	
	snr9816_init();								// snr9816串口通信初始化
	
	PS2_Init();									// PS2手柄初始化
	
	interrupt_global_enable();					// 关闭所有中断
	
	delay_ms(2000);

	reset_coordinate(&scara,X_INIT, Y_INIT, Z_INIT);	// 开始校准

	snr9816tts_set_voice("[m1]");						// 设为男声
//	
//	snr9816tts_say_sentence("ring_1");

//	snr9816tts_say_sentence("龙虾机器人");

	while(1)
	{
		delay_ms(DRIVER_RESPONSE_CYCLE);
		
		driver_gpio_loop();						// GPIO主循环
		
		ps2_loop();								// ps2手柄循环
		
		scara_uart_loop();						// 串口接收响应循环
	}
}

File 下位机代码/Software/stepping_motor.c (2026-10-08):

#include "driver_config.h"
#define func_abs(x)             ((x) >= 0 ? (x): -(x))

void motor_enable(uint8_t state)
{
	if(state == 0)
	{
		GPIO_SetBits(ENABLE_PORT,ENABLE_PIN);
	}
	else
	{
		GPIO_ResetBits(ENABLE_PORT,ENABLE_PIN);
	}
}
void FA_set_direction(uint8_t state)
{
	if(state == 0)
	{
		GPIO_SetBits(DIR_PORT,M1_DIR_PIN);
	}
	else
	{
		GPIO_ResetBits(DIR_PORT,M1_DIR_PIN);
	}
}
void SA_set_direction(uint8_t state)
{
	if(state == 0)
	{
		GPIO_SetBits(DIR_PORT,M2_DIR_PIN);
	}
	else
	{
		GPIO_ResetBits(DIR_PORT,M2_DIR_PIN);
	}
}
void Z_set_direction(uint8_t state)
{
	if(state == 0)
	{
		GPIO_SetBits(DIR_PORT,M3_DIR_PIN);
	}
	else
	{
		GPIO_ResetBits(DIR_PORT,M3_DIR_PIN);
	}
}

void FA_pwm_init(uint16_t arr, uint16_t psc)
{
	GPIO_InitTypeDef GPIO_InitStructure;
	TIM_TimeBaseInitTypeDef  TIM_TimeBaseStructure;
	TIM_OCInitTypeDef TIM_OCInitStructure;
	NVIC_InitTypeDef NVIC_InitStructure;

	RCC_APB1PeriphClockCmd(RCC_APB1Periph_TIM2, ENABLE);	//使能TIM2时钟	
	RCC_APB2PeriphClockCmd(RCC_APB2Periph_GPIOA, ENABLE);	//使能GPIOA时钟
	
	GPIO_StructInit(&GPIO_InitStructure);					//将GPIO_InitStruct中的参数按缺省值输入
	GPIO_InitStructure.GPIO_Pin = GPIO_Pin_0 ;				//PA0
	GPIO_InitStructure.GPIO_Mode = GPIO_Mode_AF_PP;			//复用推挽模式
	GPIO_InitStructure.GPIO_Speed = GPIO_Speed_50MHz;
	GPIO_Init(GPIOA, &GPIO_InitStructure);	
	
	TIM_DeInit(TIM2);										//把寄存器值设置为缺省值
	TIM_TimeBaseStructInit(&TIM_TimeBaseStructure);			//将参数设置为缺省值
	TIM_TimeBaseStructure.TIM_Period = arr; 				//设置在下一个更新事件装入活动的自动重装载寄存器周期的值
	TIM_TimeBaseStructure.TIM_Prescaler = psc; 				//设置用来作为TIMx时钟频率除数的预分频值 
	TIM_TimeBaseStructure.TIM_ClockDivision = 0; 			//设置时钟分割:TDTS = Tck_tim
	TIM_TimeBaseStructure.TIM_CounterMode = TIM_CounterMode_Up; //TIM向上计数模式
	TIM_TimeBaseStructure.TIM_RepetitionCounter=0;  		//根据TIM_TimeBaseInitStruct中指定的参数初始化TIMx的时间基数单位
	TIM_TimeBaseInit(TIM2, &TIM_TimeBaseStructure);

	TIM_OCInitStructure.TIM_OCMode = TIM_OCMode_PWM1; 
	TIM_OCInitStructure.TIM_OutputState = TIM_OutputState_Enable; 
	TIM_OCInitStructure.TIM_OCPolarity = TIM_OCPolarity_High; 
	TIM_OCInitStructure.TIM_OCIdleState = TIM_OCIdleState_Set; 
	TIM_OCInitStructure.TIM_Pulse = arr/2;					//CH1 PWM脉宽值
	TIM_OC1Init(TIM2,&TIM_OCInitStructure);
	TIM_OC1PreloadConfig(TIM2, TIM_OCPreload_Enable); 		//使能输出比较预装载寄存器
	
	//定时器2中断配置
	TIM_ITConfig(TIM2,TIM_IT_Update,ENABLE );

	NVIC_InitStructure.NVIC_IRQChannel						= TIM2_IRQn;
	NVIC_InitStructure.NVIC_IRQChannelPreemptionPriority	= 0;
	NVIC_InitStructure.NVIC_IRQChannelSubPriority			= 0;
	NVIC_InitStructure.NVIC_IRQChannelCmd					= ENABLE;
	NVIC_Init(&NVIC_InitStructure);

	TIM_ARRPreloadConfig(TIM2,ENABLE);						//使能自动重装载的预装载寄存器允许位
	TIM_Cmd(TIM2, DISABLE);
}
void SA_pwm_init(uint16_t arr, uint16_t psc)
{
	GPIO_InitTypeDef GPIO_InitStructure;
	NVIC_InitTypeDef NVIC_InitStructure;
	TIM_OCInitTypeDef TIM_OCInitStructure;
	TIM_TimeBaseInitTypeDef  TIM_TimeBaseStructure;

	RCC_APB1PeriphClockCmd(RCC_APB1Periph_TIM3, ENABLE);//使能TIM3时钟	
	RCC_APB2PeriphClockCmd(RCC_APB2Periph_GPIOB , ENABLE);//使能GPIOB时钟和复用时钟

	GPIO_StructInit(&GPIO_InitStructure);				//将GPIO_InitStruct中的参数按缺省值输入
	GPIO_InitStructure.GPIO_Pin = GPIO_Pin_0;
	GPIO_InitStructure.GPIO_Mode = GPIO_Mode_AF_PP;		//PB0
	GPIO_InitStructure.GPIO_Speed = GPIO_Speed_50MHz;
	GPIO_Init(GPIOB, &GPIO_InitStructure);
                      
	TIM_DeInit(TIM3);	//把寄存器值设置为缺省值
	TIM_TimeBaseStructInit(&TIM_TimeBaseStructure);
	TIM_TimeBaseStructure.TIM_Period = arr; 					//设置在下一个更新事件装入活动的自动重装载寄存器周期的值
	TIM_TimeBaseStructure.TIM_Prescaler = psc; 					//设置用来作为TIMx时钟频率除数的预分频值 
	TIM_TimeBaseStructure.TIM_ClockDivision = 0;				//设置时钟分割:TDTS = Tck_tim
	TIM_TimeBaseStructure.TIM_CounterMode = TIM_CounterMode_Up; //TIM向上计数模式
	TIM_TimeBaseInit(TIM3, &TIM_TimeBaseStructure);

	TIM_OCInitStructure.TIM_OCMode = TIM_OCMode_PWM1; 
	TIM_OCInitStructure.TIM_OutputState = TIM_OutputState_Enable; //使能 PWM 输出到端口
	TIM_OCInitStructure.TIM_OCPolarity = TIM_OCPolarity_High; //输出极性高
	TIM_OCInitStructure.TIM_OCIdleState = TIM_OCIdleState_Set; 
	TIM_OCInitStructure.TIM_Pulse = arr/2; //CH3 PWM 的值
	TIM_OC3Init(TIM3,&TIM_OCInitStructure);//初始化 TIM3 OC3
	TIM_OC3PreloadConfig(TIM3, TIM_OCPreload_Enable); //使能预装载寄存器

	//定时器3中断配置
	TIM_ITConfig(TIM3,TIM_IT_Update,ENABLE);

	NVIC_InitStructure.NVIC_IRQChannel = TIM3_IRQn;
	NVIC_InitStructure.NVIC_IRQChannelPreemptionPriority= 0;
	NVIC_InitStructure.NVIC_IRQChannelSubPriority = 0;
	NVIC_InitStructure.NVIC_IRQChannelCmd	= ENABLE;
	NVIC_Init(&NVIC_InitStructure);

	TIM_ARRPreloadConfig(TIM3,ENABLE);//使能自动重装载的预装载寄存器允许位
	TIM_Cmd(TIM3,DISABLE);//失能定时器
	
}
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

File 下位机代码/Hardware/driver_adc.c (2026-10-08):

#include "driver_config.h"
uint16_t inline_current_adc_value[3];
// ADC输入脚:I_A->PA0,I_B->PA1,IC->PA7,这里默认初始化三路电流传感器
void current_sensor_adc_init()
{
  	RCC_APB2PeriphClockCmd(RCC_APB2Periph_ADC1, ENABLE);	//开启ADC1的时钟
	RCC_APB2PeriphClockCmd(RCC_APB2Periph_GPIOA, ENABLE);	//开启GPIOA的时钟
	RCC_AHBPeriphClockCmd(RCC_AHBPeriph_DMA1, ENABLE);		//开启DMA1的时钟
	
	/*设置ADC时钟*/
	RCC_ADCCLKConfig(RCC_PCLK2_Div6);						//选择时钟6分频，ADCCLK = 72MHz / 6 = 12MHz
	
	/*GPIO初始化*/
	GPIO_InitTypeDef GPIO_InitStructure;
	GPIO_InitStructure.GPIO_Mode = GPIO_Mode_AIN;
	GPIO_InitStructure.GPIO_Pin = GPIO_Pin_0 | GPIO_Pin_1 | GPIO_Pin_7;;
	GPIO_InitStructure.GPIO_Speed = GPIO_Speed_50MHz;
	GPIO_Init(GPIOA, &GPIO_InitStructure);					//将PA0、PA1引脚初始化为模拟输入
	
	/*规则组通道配置*/
	ADC_RegularChannelConfig(ADC1, ADC_Channel_0, 1, ADC_SampleTime_55Cycles5);	//规则组序列0的位置，配置为通道1
	ADC_RegularChannelConfig(ADC1, ADC_Channel_1, 2, ADC_SampleTime_55Cycles5);	//规则组序列1的位置，配置为通道2
	ADC_RegularChannelConfig(ADC1, ADC_Channel_7, 3, ADC_SampleTime_55Cycles5);	//规则组序列7的位置，配置为通道3
	/*ADC初始化*/
	
	ADC_InitTypeDef ADC_InitStructure;											
	ADC_InitStructure.ADC_Mode = ADC_Mode_Independent;							
	ADC_InitStructure.ADC_DataAlign = ADC_DataAlign_Right;						
	ADC_InitStructure.ADC_ExternalTrigConv = ADC_ExternalTrigConv_None;			
	ADC_InitStructure.ADC_ContinuousConvMode = DISABLE;							
	ADC_InitStructure.ADC_ScanConvMode = ENABLE;								
	ADC_InitStructure.ADC_NbrOfChannel = 3;										
	ADC_Init(ADC1, &ADC_InitStructure);											
	
	/*DMA初始化*/
	DMA_InitTypeDef DMA_InitStructure;											
	DMA_InitStructure.DMA_PeripheralBaseAddr = (uint32_t)&ADC1->DR;				
	DMA_InitStructure.DMA_PeripheralDataSize = DMA_PeripheralDataSize_HalfWord;	
	DMA_InitStructure.DMA_PeripheralInc = DMA_PeripheralInc_Disable;			
	DMA_InitStructure.DMA_MemoryBaseAddr = (uint32_t)inline_current_adc_value;	
	DMA_InitStructure.DMA_MemoryDataSize = DMA_MemoryDataSize_HalfWord;			
	DMA_InitStructure.DMA_MemoryInc = DMA_MemoryInc_Enable;						
	DMA_InitStructure.DMA_DIR = DMA_DIR_PeripheralSRC;							
	DMA_InitStructure.DMA_BufferSize = 3;										
	DMA_InitStructure.DMA_Mode = DMA_Mode_Circular;								
	DMA_InitStructure.DMA_M2M = DMA_M2M_Disable;								
	DMA_InitStructure.DMA_Priority = DMA_Priority_Medium;						
	DMA_Init(DMA1_Channel1, &DMA_InitStructure);								
		
	/*DMA和ADC使能*/
	DMA_Cmd(DMA1_Channel1, ENABLE);							//DMA1的通道1使能
	ADC_DMACmd(ADC1, ENABLE);								//ADC1触发DMA1的信号使能
	ADC_Cmd(ADC1, ENABLE);									//ADC1使能
	
	/*ADC校准*/
	ADC_ResetCalibration(ADC1);								//固定流程，内部有电路会自动执行校准
	while (ADC_GetResetCalibrationStatus(ADC1) == SET);
	ADC_StartCalibration(ADC1);
	while (ADC_GetCalibrationStatus(ADC1) == SET);
	
	/*ADC触发*/
	ADC_SoftwareStartConvCmd(ADC1, ENABLE);	//软件触发ADC开始工作，由于ADC处于连续转换模式，故触发一次后ADC就可以一直连续不断地工作
}
void battery_adc_init() 
{
    // 使能GPIOB和ADC2时钟
    RCC_APB2PeriphClockCmd(RCC_APB2Periph_GPIOB | RCC_APB2Periph_ADC2, ENABLE);
    
    // 配置ADC时钟分频，ADC最大时钟不能超过14MHz
    // 这里假设APB2时钟为72MHz，分频为6，得到12MHz
    RCC_ADCCLKConfig(RCC_PCLK2_Div6);
    
    GPIO_InitTypeDef GPIO_InitStructure;
    // 配置PB0为模拟输入模式
    GPIO_InitStructure.GPIO_Pin = GPIO_Pin_0;
    GPIO_InitStructure.GPIO_Mode = GPIO_Mode_AIN;  // 模拟输入，无需上拉下拉
    GPIO_Init(GPIOB, &GPIO_InitStructure);
    
    ADC_InitTypeDef ADC_InitStructure;
    // ADC工作在独立模式
    ADC_InitStructure.ADC_Mode = ADC_Mode_Independent;
    // 关闭扫描模式（单通道无需扫描）
    ADC_InitStructure.ADC_ScanConvMode = DISABLE;
    // 关闭连续转换模式（使用单次转换）
    ADC_InitStructure.ADC_ContinuousConvMode = DISABLE;
    // 不使用外部触发，采用软件触发
    ADC_InitStructure.ADC_ExternalTrigConv = ADC_ExternalTrigConv_None;
    // 数据右对齐
    ADC_InitStructure.ADC_DataAlign = ADC_DataAlign_Right;
    // 转换通道数量为1
    ADC_InitStructure.ADC_NbrOfChannel = 1;
    ADC_Init(ADC2, &ADC_InitStructure);
    
    // 配置ADC2的通道8（PB0），转换顺序为1，采样时间为55.5个周期
    ADC_RegularChannelConfig(ADC2, ADC_Channel_8, 1, ADC_SampleTime_55Cycles5);
    
    // 使能ADC2
    ADC_Cmd(ADC2, ENABLE);
    
    // ADC校准
    ADC_ResetCalibration(ADC2);
    while(ADC_GetResetCalibrationStatus(ADC2));  // 等待校准寄存器重置完成
    
    ADC_StartCalibration(ADC2);
    while(ADC_GetCalibrationStatus(ADC2));  // 等待校准完成
}
// ADC采集附带均值滤波
uint16_t battery_read_adc_value(uint8_t n)
{
	uint32_t sum = 0;
	for(uint8_t i = 0;i < n;i++)
	{
	    // 启动ADC2软件转换
		ADC_SoftwareStartConvCmd(ADC2, ENABLE);
		// 等待转换完成（轮询方式）
		while(!ADC_GetFlagStatus(ADC2, ADC_FLAG_EOC));
		// 清除转换完成标志位
		ADC_ClearFlag(ADC2, ADC_FLAG_EOC);
		sum += ADC_GetConversionValue(ADC2);
	}

    // 返回转换结果
    return sum/n;
}

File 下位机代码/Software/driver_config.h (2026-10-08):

#ifndef __DRIVER_CONFIG_H_
#define __DRIVER_CONFIG_H_

#include "tool.h"
#include "delay.h"
#include "serial.h"
#include "driver_gpio.h"
#include "driver_adc.h"
#include "flash.h"
#include "interface.h"
#include "interrupt.h"
#include "stepping_motor.h"
#include "driver_gpio.h"
#include "snr9816.h"
#include "serial_lcd.h"
#include "ps2.h"
#include "scara.h"
#include "scara_uart.h"

#define  TIM_CLOCK_FREQ			72000000			// 时钟主频				
// 步进电机参数
#define  STEPPING_ANGLE			1.8					// 步进角，单位度
#define  SUBDIVISION			32					// 细分数，常见32细分，16细分，8细分等	
// 机械臂参数
#define  FA_REDUCTION_RATIO 	5.1 				// 主臂减速比，原来是6
#define  SA_REDUCTION_RATIO 	3.9 				// 副臂减速比，原来是5
#define  LEAD 					2.0 				// z轴丝杆导程,2mm
#define  L_FA 					177.0 				// 主臂长度，单位mm
#define  L_SA 					177.0 				// 副臂长度，单位mm
#define  L_FA_2 				(L_FA * L_FA)
#define  L_SA_2 				(L_SA * L_SA)

// 初始坐标
#define  X_INIT					177
#define  Y_INIT					-177
#define  Z_INIT					25
#define  Z_UP					50
#define  Z_DOWN					25

// 关节限幅
#define  FA_ANGLE_MAX					90
#define  FA_ANGLE_MIN					-90		
#define  SA_ANGLE_MAX					180
#define  SA_ANGLE_MIN					15
#define  Z_HEIGHT_MAX					83					// 最高为100mm,保险最高位96mm
#define  Z_HEIGHT_MIN					2					// 最低为0mm,保险最低为2mm


#define  M_PI 3.14159265358979323846
#define  RAD2DEG (180.0 / M_PI)

#define  DRIVER_RESPONSE_CYCLE  		10

#define  ELECTROMAGNET					(0)
#define  AIRPUMP						(1)
#define  TOOL							AIRPUMP

#define  ELECTROMAGNET_DIR				0
#define  ELECTROMAGNET_DUTY				1000-1 	// 电磁铁占空比，满占空比为1000



#endif

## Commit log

2026-10-08 初始化仓库
    [1394 pcb.sldprt, 1394 pcb2.sldprt, 1位拨码开关-贴片.sldprt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]
2026-10-08 小改一下
2026-10-08 补全了URDF模型
    [Link1.STL, Link2.STL, Link3.STL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]
2026-10-13 补充了物料清单
2026-10-16 上传PPT
2026-10-21 上传修改
2026-11-09 新增项目
